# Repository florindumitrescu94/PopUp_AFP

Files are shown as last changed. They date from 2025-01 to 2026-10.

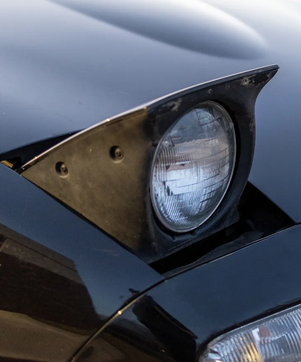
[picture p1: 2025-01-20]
PopUp_AFP/popup.png

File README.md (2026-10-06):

front

ASCOM connected DIY Automatic Flat Panel with Arduino and LED Strip.

Linux / INDI users: see [`PopUp_AFP_INDI/`](PopUp_AFP_INDI/) for a native INDI driver talking to the same Arduino firmware — no ASCOM/Windows required.

While a number of DIY flat panel projects exist online already, I wanted to make my own.
This is a flat panel with a spin: The motor and circuit board are on the panel itself, not on the telescope mounted base.
This allows the whole thing to be more low profile than existing designs. One advantage is the fact that no fragile wires will flex during operation. While there still are some wires present (the USB and Power cables), these wires can be swapped out at any time easily and without the need to open up the device.

This functions like any other flat panel (sans the dew heater available on some) and can be used in any imaging software that has ASCOM capabilities.

The BOM is fairly short: 
  - An Arduino Nano
  - a small buck converter to get 5V from 12V https://vi.aliexpress.com/item/1005007092498838.html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
  - TD-7120MG 270 degrees stepper motor https://vi.aliexpress.com/item/1005007475952814.html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
  - LR2905 N-MOSFET (SMD mounted)
  - a through-hole ferrite bead
  - 10k and 100 ohms SMD 0805 resistors
  - 1 SS545L SMD diode 
  - 1 through hole current limiting resistor for the LED strip (I went with 330 ohms, pick your own value based on your needs.
  - a length of 8mm wide natural white COB led strip (any 12V COB LED Strip will work. I sourced mine locally from a store, you could order one from AliExpress and you'd probably get the same thing).
  - a 12W round LED light fixture (links below). We will use this for the internal diffuser: https://vi.aliexpress.com/item/33054747819.html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

  To avoid flickering, the frequency of pin 3 has been increased to 31kHz and a ferite bead has been introduced in the circuit between the switching MOSFET and the LED strip. A flyback diode has been added to avoid any spikes created by the ferrite bead. It provides banding-free flats down to 0.1s. 

  The light panel is based around the 12W LED light diffuser. Once you get the light fixture, unscrew the 6 screws on the back and remove the round metal cover. Inside, you should find a round piece of white foam, a white plastic reflector, a disk of transparent acrylic and a white plastic translucent diffuser (the outside part). This is all we need from this light fixture.

The arms and base are printed in 3 parts: the two arms and the cross-brace that holds them in place with screws. Once you print the parts, align the two arms and the crossbrace, then drill 2mm holes in the brace through the already modeled holes in the arms. Then, insert either M3 screws and tighten down. Avoid overtightnening to not strip out the plastic. If you want, you can drill out bigger holes and use heat-set inserts. This base will be held in place on the telescope using metalic hose clamps. Make sure to stick some self-adhesive velvet on the dew shield to avoid scratching the metal. 



Print the four parts of the panel (BASE,RING,SPACER and SUPPORT), then assemble as follows:

- use 6 x 8mm M3 screws and nuts and connect the BASE to the SUPPORT using pre-modeled holes in the BASE. You can add some epoxy on the screw heads to stick them to the base for ease of later adjustment.
- solder two wires to the LED strip, the stick it around the inside of the BASE. You will need to overlap the last 2-3 mm of the strip after cutting it on the closest cutting point. To do that strip back the 2-3mm off the silicone cover from the LED strip and stick the end with the wires on top of that. Thread the wires thorugh the hole in the center of the BASE (it comes out through the SUPPORT into the electronics chamber)
- Put the foam piece in the center. You might want to cut a channel for the wires into the foam.
- Add the thin white reflector
- add the acrylic disk in the center
- add the 2.2mm 3d printed spacer ring
- put the translucent white diffuser on top
- add the 3d printed ring, align the screw holes with the ones in the base and screw in 6 x 4mm M3 bolts. You can use the bolts that came with the servo motor, since we will be using different bolts to secure the arm to the servo.

This concludes building the panel itself.

Next, cut, etch, drill and assemble the PCB, then put it inside the electronics case (PCB is in the Construction folder.
Schematic

I suggest cutting a 40mm x 60mm board so it fits snuggly against the walls of the SUPPORT. Solder the servo motor wires and the LED strip wires to the PCB. 
Then, drill four M3 holes in the PCB and the plastic risers, then screw the PCB down, avoiding overtightnening the screws. Make sure you print the risers with 100% infil.
Secure the SERVO in the SUPPORT bracket using the plastic screws that came supplied with the motor. 
Print the COVER, then secure it using M3 bolts, two on top and two on the sides.

At this point, the flat panel can be used as is. If you intend to build and use the panel as a manual panel, instead of a motorised one, you can follow the same procedure, but skip adding the motor. Skip the next step if you want this.

Mounting everything together:

Add the two metal wheels to the servo. Secure the one on the driven axle of the servo using the included M3 bolt. Use another M3 bolt for the support axle (the black plastic one that does not rotate). 
Next, loosely mount the ARMS and CROSS-BRACE to the telescope, then slide the SERVO motor shafts between the two arms. The arms have slotted holes, so the 0 position can be adjusted (the splined shaft holes do not end up perfectly aligned at 90 degrees).
DO NOT INSERT THE SCREWS MOUNTING THE ARMS TO THE SERVO YET! We need to make sure where the servo is currently positioned (0 to 270 degrees).
Print the cable clips and glue them to the ARM you want you cables to be attached to (use superglue or epoxy). 

Programing the board and driver setup:

Open Arduino IDE on your computer and connect the Arduino. Download the INO file from the release page and open it in the IDE. Select the correct COM port and board type, then upload the code. 
Download and install the ASCOM driver from the release page. 
Once installed, open N.I.N.A (or whatever aquisition software you are using), then select PopUp AFP. Warning: due to some reasons unknown to me, the ASCOM driver installer creates two entries in the dropdown selection menu. One of them works, but one of them is not registered with ASCOM, so it won't work. Check to see whcih one works and use that one. Open the properties, select the right COM port and set the Closed and Open positions (0 to 270 degrees), then hit Ok, then Connect to the device. 

Once connected, it's time for testing. Plug in a 12V power source and toggle the light panel on and off, setting different light levels (0 - 255). 
If you've used a jumper instead of a limiting resistor, the 255 value will be extremely bright. Now it's time to check and chose the right current limiting resistor for your situation (I've used 330 ohms and it works fine).
Then, click Open and Close and watch for movement of the stepper motor (remember, we do not have any screws mounted, so only the stepper flanges will move, but not the whole panel). 

Setting the Closed and Open Positions (angles) and the physical 0 position.

Earlier, when setting up the driver in NINA, we had to select an Open and Closed position for the panel. The Closed position should always be 0, but you can alter that in the unlikely eventuality you actually need to change it. 
Now, open the panel manually and check how much can it open. Measure the angle starting from the 0 position, then set that as Open position.
When there's no obstruction to the panel, it can fully open. Set the Open position to 270. This will open the panel fully, then set it parralel to the telescope


If theres any obstruction or, for any other reason, you need to open the panel lees than the full 270 degrees (which, with the TD7120MG is never really 270, more like 250-260), set the desired angle as Open position.





Set the two values, then connect to the device. Once connected, click the Close button.

Point your telescope at zenith, then close the panel manually. You might also need to adjust the position of the telescope-side mounting so that the panel can be flush with the dew shield's opening. 
At this point, you can insert the 8  M3 x 10mm bolts throught he slots in the arms and tighten them down. You can use some lock washers between the screw head and the arms, so it will bite into the plastic and not move. 

Once you have tightened the screws, click the Open button. The panel should now move to its' set max position. 

And..... that's it! You're ready to use the flat panel. 

Note on LED strips: 
I have used a warm white LED strip. While it looks very yellow-ish, the emissions in Ha and S2 are more intense than with cool/natural white. You can test and go with whichever colour temperature you might find fitting for your situation.

You can find the PCB copper file, EasyEDA project, Fusion 360 project and STL files inside the "Construction" folder

Note on Limiting Resistor:

During my time testing the panel, I've found that not using any current limiting resistor might work for a slow system, like mine, at f7. However, if you have a faster scope, you might benefit from adding a current limiting resistor instead of a jumper, so that you don't blow out the Luminance flats at 1% power.

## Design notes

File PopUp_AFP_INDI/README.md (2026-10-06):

# PopUp AFP — INDI driver

INDI driver for the PopUp AFP pop-up dust cover + dimmable flat panel, ported
from this repo's ASCOM `ICoverCalibrator` driver (`PopUp_AFP/CoverCalibratorDriver/`)
so the panel can be used from INDI/Ekos/KStars on Linux instead of (or
alongside) Windows + ASCOM.

It talks to the same Arduino sketch — `PopUp_AFP_Arduino/PopUp_AFP_Arduino_V2_CURRENT/PopUp_AFP_Arduino_V2.ino`
— over the same 9600-baud, `>CMD#`-framed serial protocol. No firmware changes
are required; flash the Arduino exactly as the main README already describes.

## Building

Dependencies: an INDI installation with headers (`libindi-dev`), cmake, a C++17
compiler, and pkg-config.

```bash
sudo apt install libindi-dev indi-bin cmake build-essential pkg-config
```

```bash
mkdir build && cd build
cmake ..
make
sudo make install
```

`make install` drops the driver at `/usr/local/bin/indi_popup_afp` and its
driver descriptor at `/usr/share/indi/indi_popup_afp.xml` — the two locations
a **native** `indiserver`/INDI Web Manager install scans automatically, so
nothing else needs registering there.

If `/dev/ttyUSB*` or `/dev/ttyACM*` isn't writable by your user, add yourself
to the serial port's owning group (usually `dialout`) and re-login:

```bash
sudo usermod -aG dialout $USER
```

### KStars installed as a Flatpak

If KStars/Ekos is a Flatpak (`org.kde.kstars` — increasingly the default way
it's distributed on Linux), the above is not enough, for two reasons:

1. **It doesn't read `/usr/share/indi/*.xml` at all.** Its Auxiliary driver
   list for a custom driver comes from a `customdrivers` table in its own
   SQLite db (`~/.var/app/org.kde.kstars/data/kstars/userdb.sqlite`), normally
   populated via the "add a custom driver" control in the Ekos Profile
   Editor's Auxiliary dropdown (enter Name/Label/Family `Auxiliary`/Exec
   `indi_popup_afp`/Version `1.0`).
2. **The sandbox can't see `/usr/local/bin`**, even with the Flatpak's broad
   `host` filesystem permission — its `/usr` belongs to the KDE runtime, not
   the host, so `indiserver` fails to exec the driver by name and the device
   just hangs (Ekos shows the device icon stuck, never reaching "connected").
   `$HOME` *is* visible to the sandbox, so install the binary there instead
   and give the custom driver's Exec field that **absolute path**, e.g.:

   ```bash
   mkdir -p ~/.local/bin
   cp build/indi_popup_afp ~/.local/bin/indi_popup_afp
   ```

   then set Exec to `/home/<you>/.local/bin/indi_popup_afp` rather than the
   bare `indi_popup_afp`, in the Ekos custom-driver dialog.

## Using it

Once installed, "PopUp AFP" appears under the Auxiliary device group in any
INDI client. Connect, set the serial port on the Connection tab if it isn't
already `/dev/ttyUSB0`, and the Main Control tab gets:

- **Cover Park / UnPark** — closes/opens the pop-up cover (`>CLOSE#` / `>OPEN#`)
- **Flat Light Control** on/off, plus a 0-255 **Flat Field Light Level** —
  matches the ASCOM driver's `CalibratorOn(Brightness)` / `CalibratorOff()`

The Options tab has **Servo Calibration** (Open/Closed, in degrees 0-270),
replacing the ASCOM SetupDialog's Open/Closed position fields — same values
the main README has you set in NINA (fully open = 270, closed = 0). These are
re-sent to the Arduino on every connect, since the firmware keeps them in RAM,
not EEPROM.

## Known firmware limitation

`AbortCap()` sends `>HALT#`, but `PopUp_AFP_Arduino_V2.ino`'s
`processSerialCommand()` has no `HALT` case today, so it's a no-op on the
device — same as the ASCOM driver's `HaltCover()`. Abort will start working on
its own the day the firmware grows a case for it; no driver change needed.

## What's not yet verified

This was built and compiled against a real `libindi-dev` and passed a smoke
test of the INDI property handshake, but has not been run against the actual
Arduino. Before trusting it on a real panel, verify:

- the serial port name/permissions on the test machine
- that `OPEN`/`CLOSE` actually move the cover through its full range at the
  configured servo angles
- that brightness changes while the light is already on take effect
  immediately (vs. only on the next `EnableLightBox(true)`)

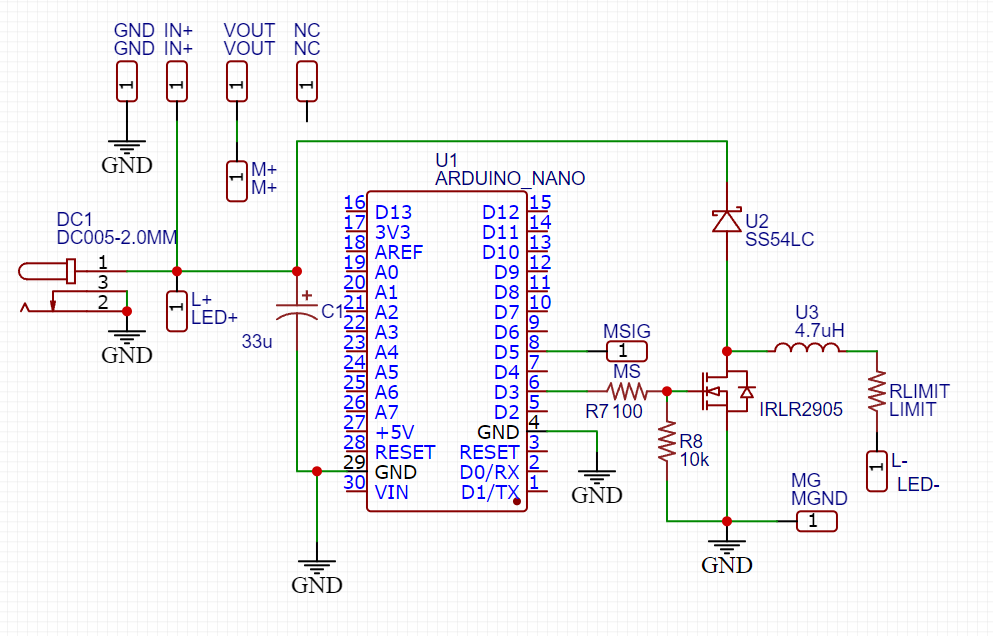
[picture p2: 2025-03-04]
Construction/V2_CURRENT/Schematic.png

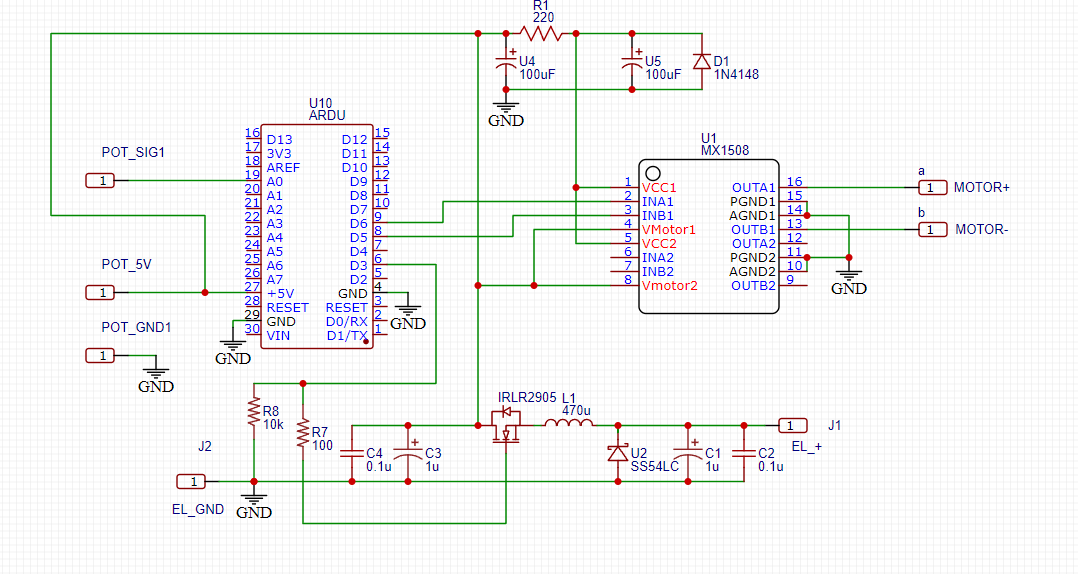
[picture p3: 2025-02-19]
Construction/schematic.png

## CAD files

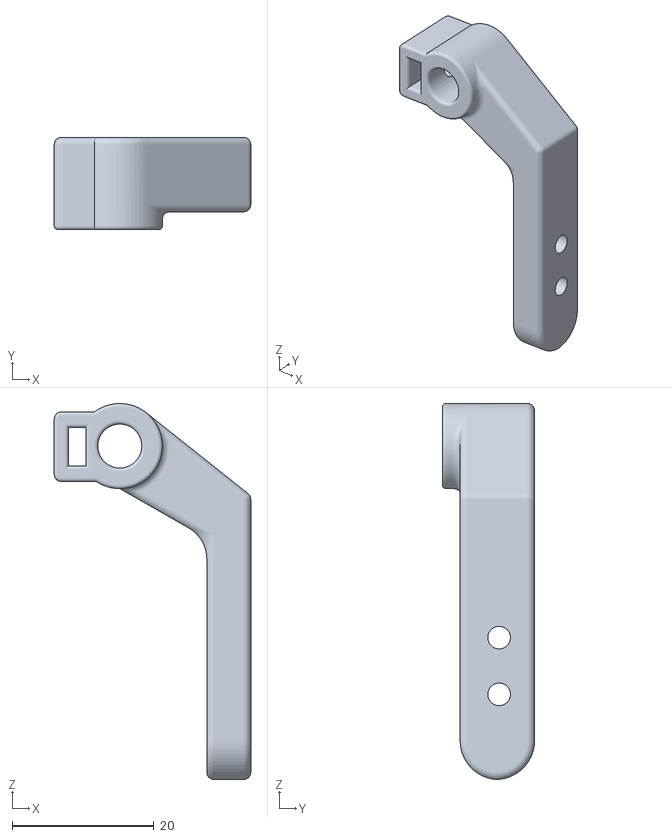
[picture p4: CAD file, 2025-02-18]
Construction/Pop_Up_Arm_Pot_model.stl
27.7 x 13.0 x 53.0

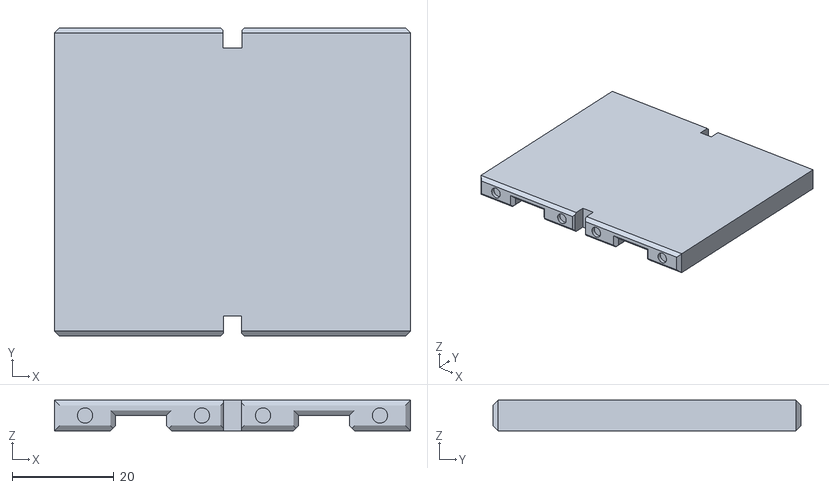
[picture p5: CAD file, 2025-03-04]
Construction/V2_CURRENT/SLT_Files/CROSS_BRACE.stl
70.0 x 60.6 x 6.00

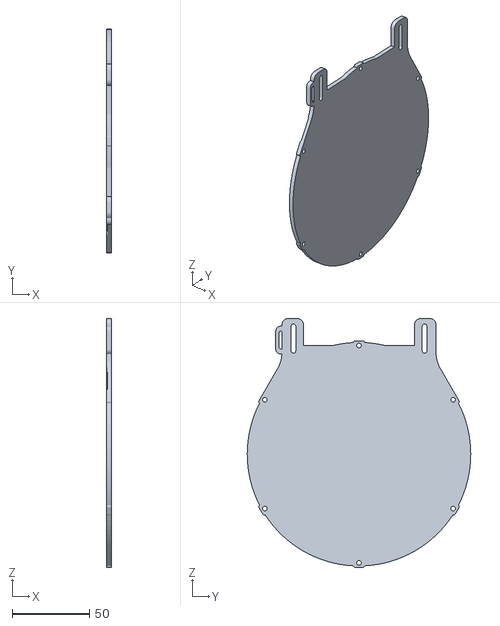
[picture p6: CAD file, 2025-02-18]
Construction/Pop_Up_Base_model.stl
3.00 x 145.0 x 161.5

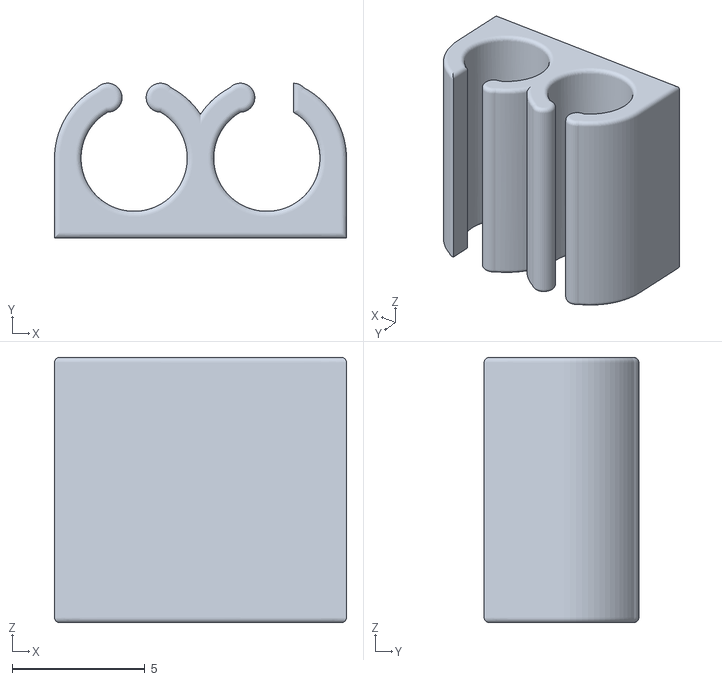
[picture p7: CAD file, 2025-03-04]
Construction/V2_CURRENT/SLT_Files/CLIPS.stl
11.0 x 5.83 x 10.0

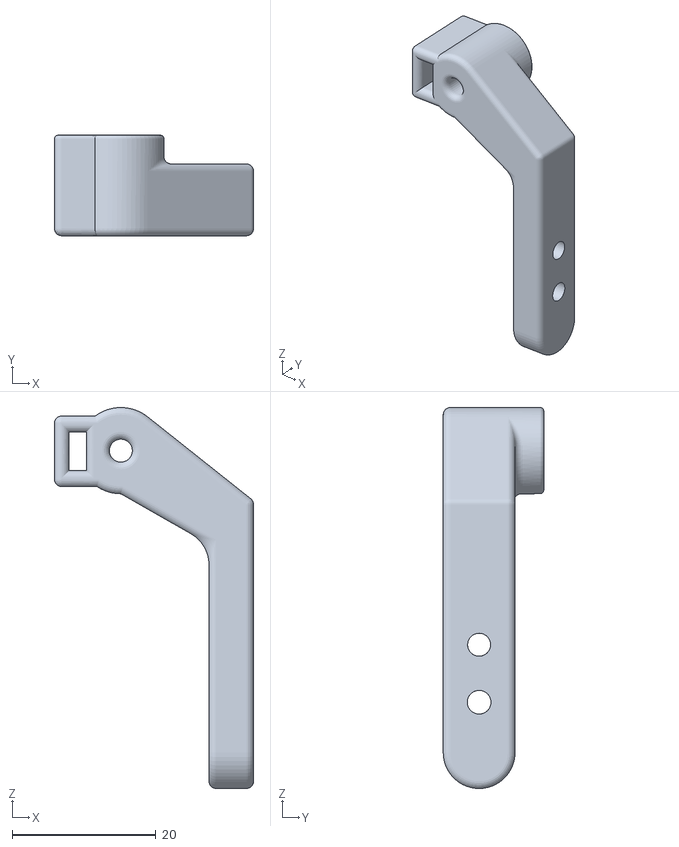
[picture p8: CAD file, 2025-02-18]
Construction/Pop_Up_ArmMotor_model.stl
27.7 x 14.0 x 53.0

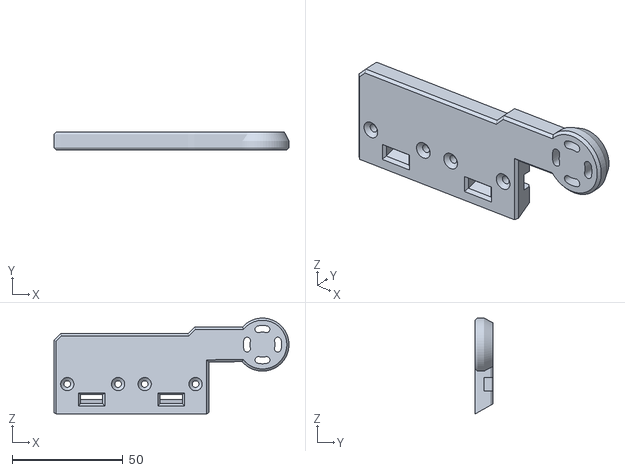
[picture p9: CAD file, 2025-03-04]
Construction/V2_CURRENT/SLT_Files/ARM_R.stl
106.2 x 8.00 x 43.3

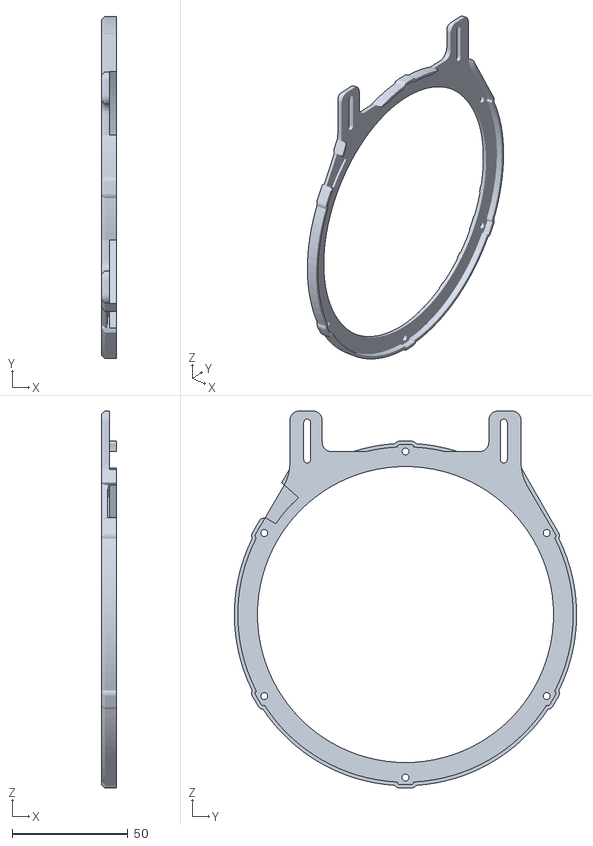
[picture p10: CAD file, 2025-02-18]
Construction/Pop_Up_Ring_model.stl
6.50 x 148.0 x 163.0

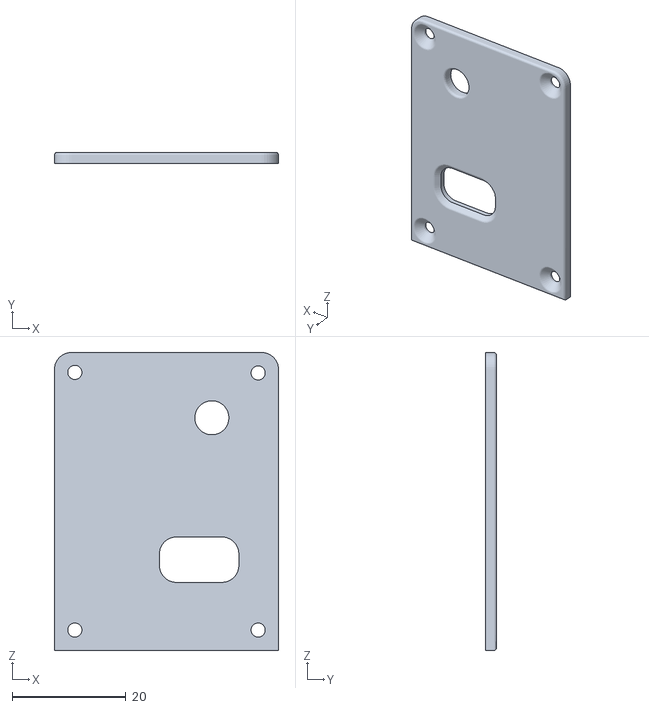
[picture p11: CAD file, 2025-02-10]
Construction/Pop_Up_EndCap_model.stl
39.5 x 2.00 x 52.5

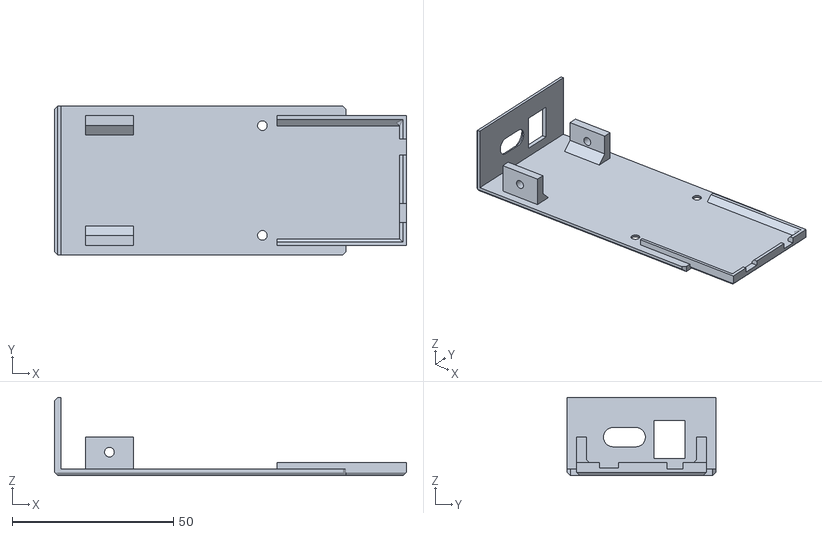
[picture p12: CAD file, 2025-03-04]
Construction/V2_CURRENT/SLT_Files/COVER.stl
109.2 x 46.2 x 24.2

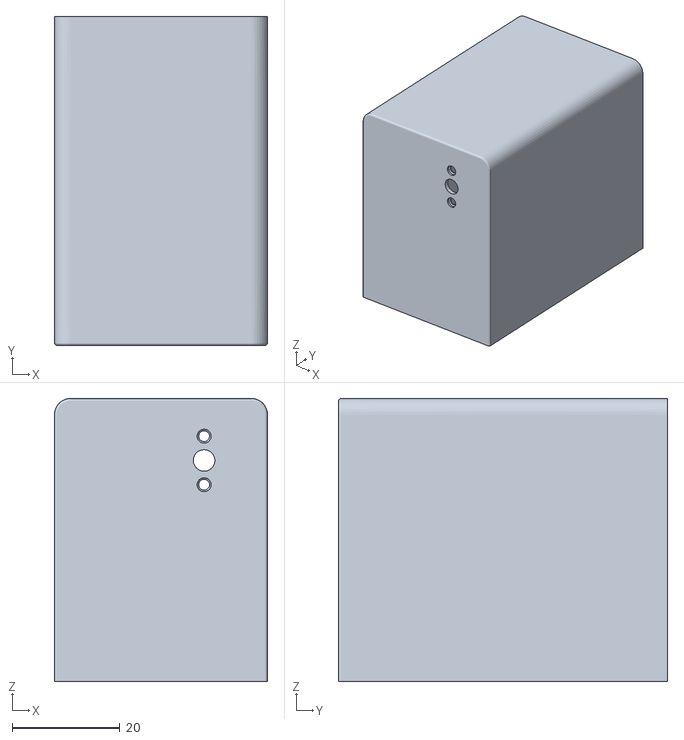
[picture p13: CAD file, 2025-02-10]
Construction/Pop_Up_Body_model.stl
39.5 x 61.0 x 52.5

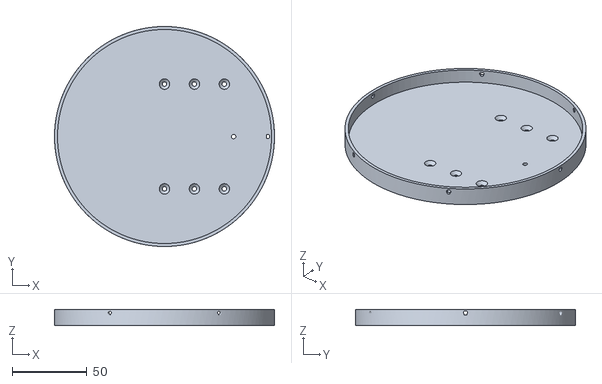
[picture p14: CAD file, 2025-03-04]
Construction/V2_CURRENT/SLT_Files/BASE.stl
147.0 x 147.0 x 11.0

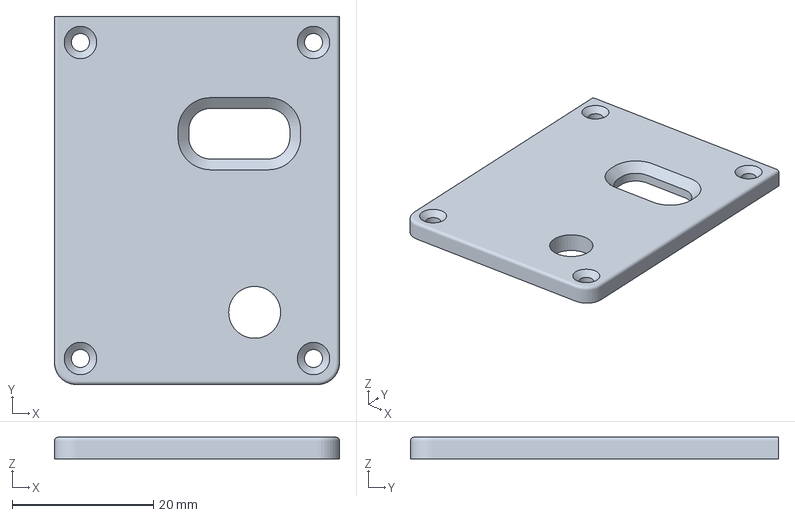
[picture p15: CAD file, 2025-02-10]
Construction/potentiometer_cap_102.3mf
40.3 x 52.0 x 3.06 mm

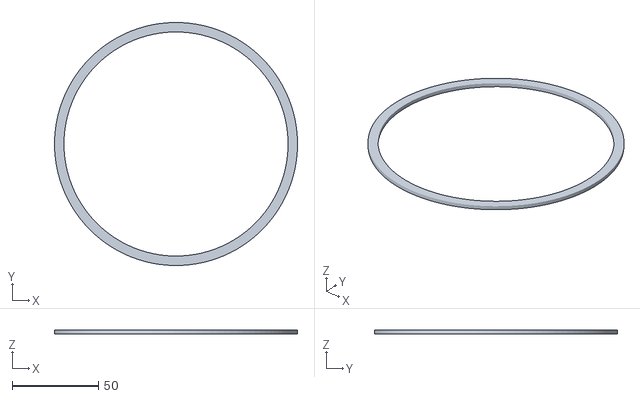
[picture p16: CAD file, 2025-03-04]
Construction/V2_CURRENT/SLT_Files/SPACER.stl
141.0 x 141.0 x 2.20

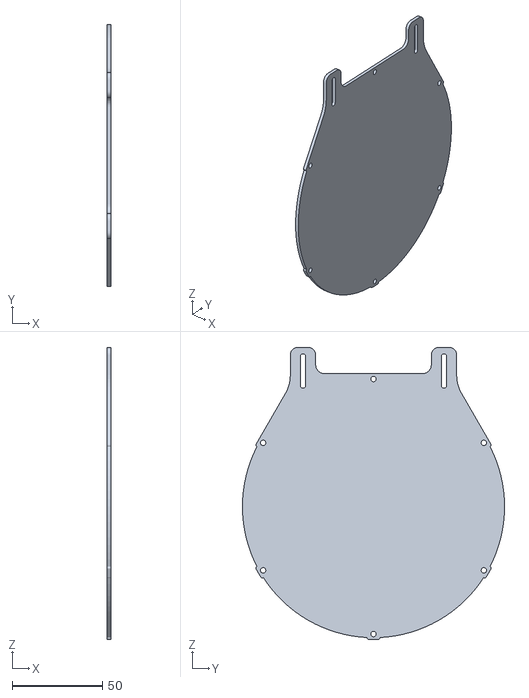
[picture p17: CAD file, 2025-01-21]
Construction/Pop_Up_Plexiglass_model.stl
2.00 x 145.0 x 161.5

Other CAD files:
Construction/V2_CURRENT/SLT_Files/ARM_L.stl
Construction/V2_CURRENT/SLT_Files/RING.stl
Construction/V2_CURRENT/SLT_Files/SUPPORT.stl
Construction/V2_CURRENT/PopUp_V2.f3z

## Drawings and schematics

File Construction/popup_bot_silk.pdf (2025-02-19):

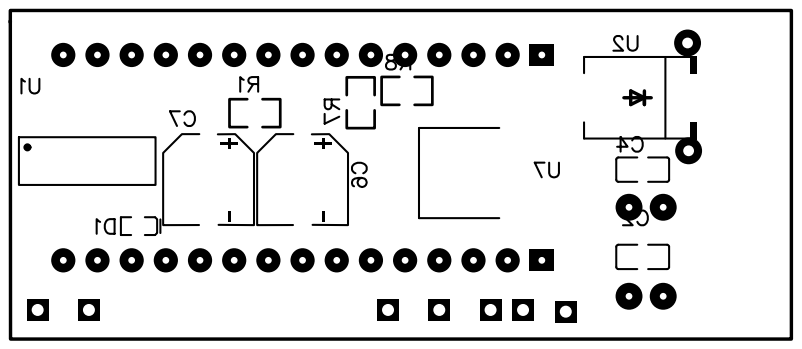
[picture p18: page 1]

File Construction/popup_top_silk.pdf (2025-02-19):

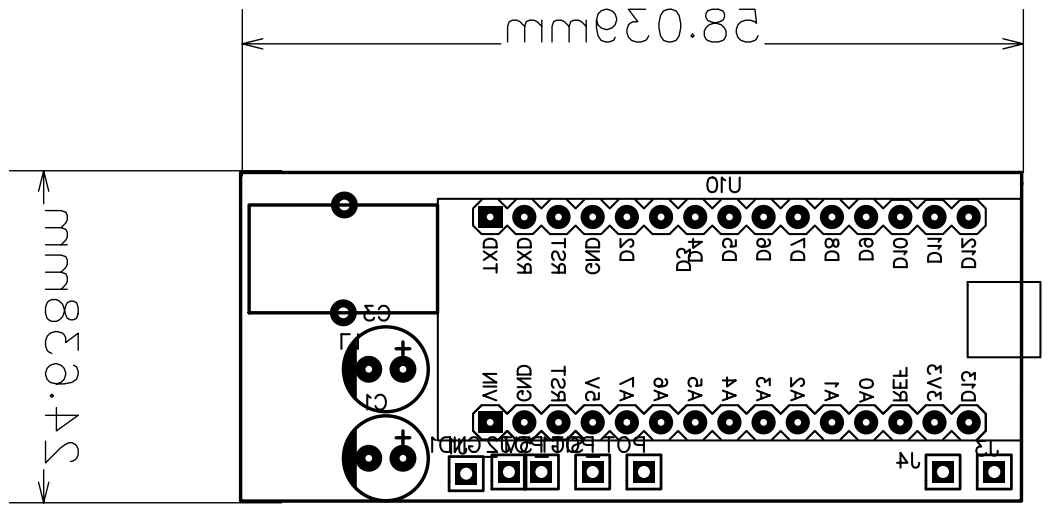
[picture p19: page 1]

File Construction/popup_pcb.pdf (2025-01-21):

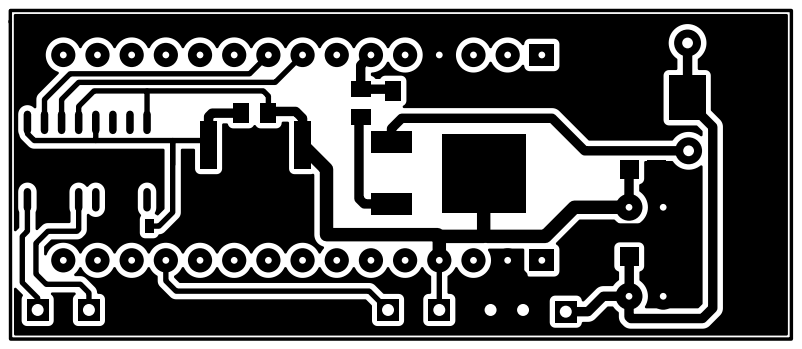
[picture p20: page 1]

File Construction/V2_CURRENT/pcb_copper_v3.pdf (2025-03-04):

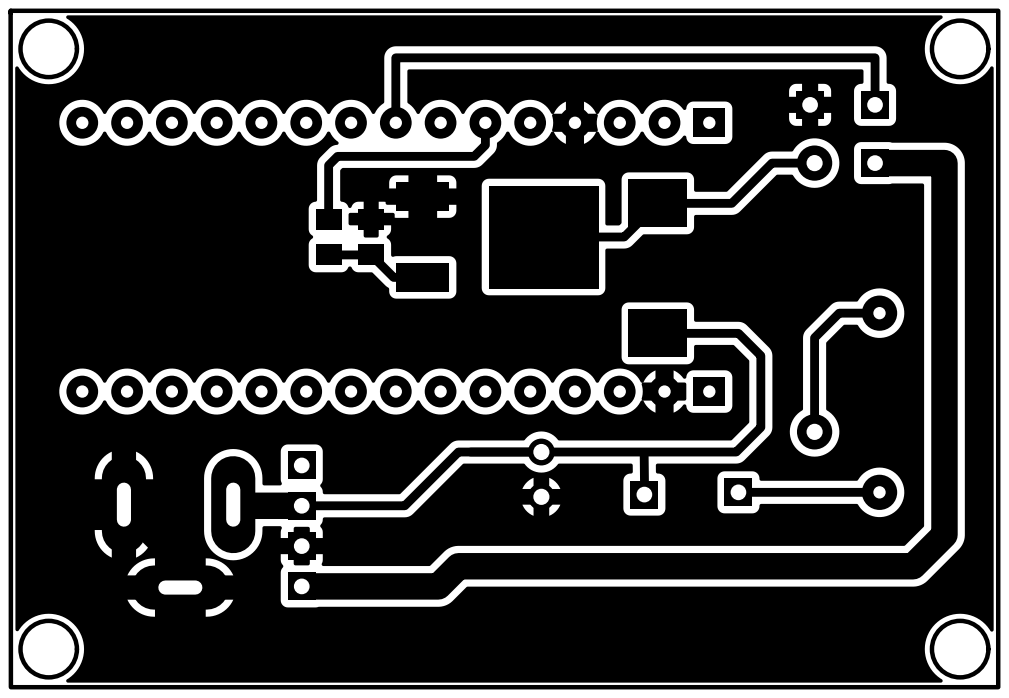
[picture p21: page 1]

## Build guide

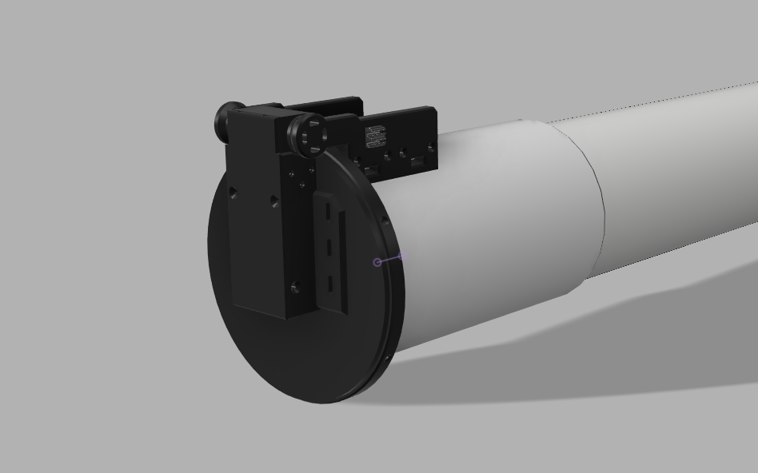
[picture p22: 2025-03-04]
Construction/V2_CURRENT/Render/front.png

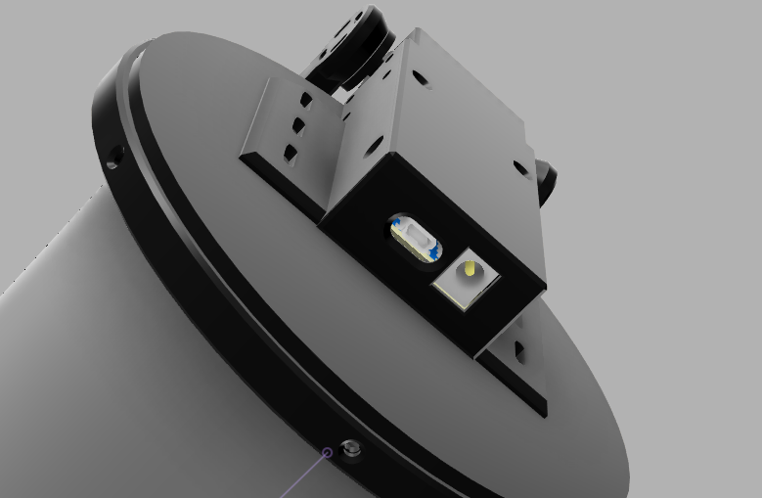
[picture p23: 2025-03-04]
Construction/V2_CURRENT/Render/ports.png

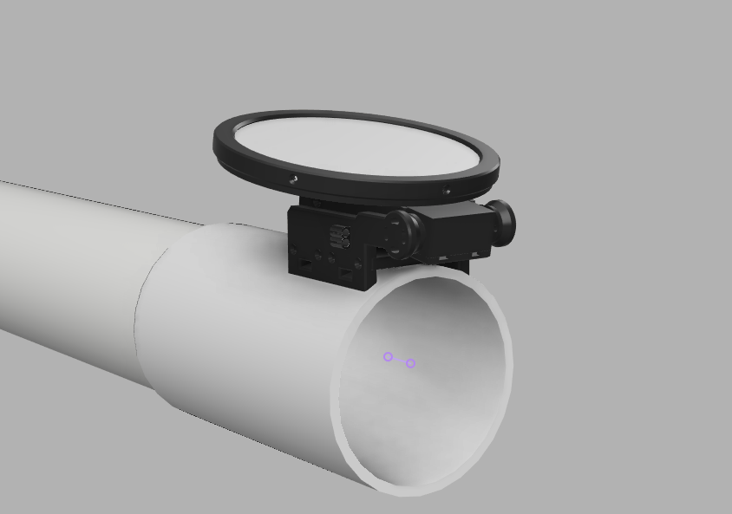
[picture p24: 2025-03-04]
Construction/V2_CURRENT/Render/Opened.png

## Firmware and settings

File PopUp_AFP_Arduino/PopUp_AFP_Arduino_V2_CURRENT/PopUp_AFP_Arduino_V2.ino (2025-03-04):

#include <math.h>
#include <Servo.h>
#include <EEPROM.h>
#define MOTOR 5
#define LIGHT 3
#define QUEUELENGTH         10             // number of commands that can be saved in the serial queue
#define MAXCOMMAND          42            // max length of a command
#define EOFSTR              '\n'
#define EOCOMMAND           '#'           // defines the end character of a command
#define SOCOMMAND           '>'           // defines the start character of a command
#define ADDR 1 // defines eeprom address

Servo PanelServo;
int panel_light=0; // State for panel light
int eeprom_position = 0; // state for EEPROM position
int panel_brightness=0; // Value for panel light 0-255
int panel_position;
int panel_state=0; //0 = Closed. 1 = Open 2 = Unknown 3 = Error 4 = Moving
int panel_closed_pos=0; // define close position
int panel_open_pos=270; // define open position
int target_state = 3; // used to hold target state (close = 0 , open = 1, done = 3, halt  = 4). Initialize with 3
char* queue[QUEUELENGTH];
int queueHead = -1;
int queueCount = 0;
int idx = 0;                              // index into the command string
String line;       

char* pop() {
  --queueCount;
  return queue[queueHead--];
}


void push(char command[MAXCOMMAND]) {
  queueCount++;
  queueHead++;
  strncpy(queue[queueHead], command, MAXCOMMAND);
}

void setup() {
  TCCR2B = TCCR2B & B11111000 | B00000001;
  pinMode(LIGHT,OUTPUT);
  pinMode(MOTOR,OUTPUT);
  analogWrite(LIGHT,0); // Set panel light to off
  eeprom_position = EEPROM.read(ADDR);
  if (eeprom_position == 1) PanelServo.write(panel_open_pos);
  if (eeprom_position == 0) PanelServo.write(panel_closed_pos);
  PanelServo.attach(MOTOR); // Attach servo
  panel_state = 2; // Panel position will be unkown at beginning;
  for ( int i=0; i < QUEUELENGTH; i++)
  queue[i] = (char*)malloc(MAXCOMMAND);
  line.reserve(MAXCOMMAND);
  Serial.begin(9600); // begin seral comm over com port
  Serial.flush();
}

void clearSerialPort() {
  while ( Serial.available() )
    Serial.read();
}

// SerialEvent occurs whenever new data comes in the serial RX.
// you should really consider a start of command character.
void serialEvent() {

  // '#' ends the command, do not store these in the command buffer
  // read the command until the terminating # character
  char buf[MAXCOMMAND];
  while ( Serial.available() )
  {
    char inChar = Serial.read();
    switch ( inChar )
    {
      case '>':     // soc, reinit line
        // memset(line, 0, MAXCOMMAND);
        line = "";
        idx = 0;
        break;
      case '#':     // eoc
        line.toCharArray(buf, MAXCOMMAND);
        idx = 0;
        push(buf);
        break;
      default:      // anything else
        if ( idx < MAXCOMMAND - 1) {
          line += inChar;
        }
        break;
    }
  }
}

void processSerialCommand(){
   if ( queueCount == 0 )
    return;

  String cmd = String(pop());
  if (cmd == "OPEN")
  {
   PanelServo.write(panel_open_pos);
   panel_state = 1;
   EEPROM.write(ADDR,panel_state);
  }
  else if (cmd == "CLOSE")
  {
    PanelServo.write(panel_closed_pos);
    panel_state = 0;
    EEPROM.write(ADDR,panel_state);
  }
  else if (cmd.substring(0,7) == "LIGHTON") 
  {
      panel_brightness = (cmd.substring((cmd.indexOf('_')+1),(cmd.indexOf('_')+4)).toInt());
      analogWrite(LIGHT,panel_brightness); // turn on light with set brightness
      panel_light = 1;
      //Serial.print(panel_light);
      //Serial.println("#");
  }
  else if (cmd == "LIGHTOFF") 
  {
      analogWrite(LIGHT,0); // turn on light with set brightness
      panel_light = 0;
  }
  
  else if (cmd == "GETLIGHTSTATE")
  {
    Serial.print(panel_light);
    Serial.print("#");
  }
  else if (cmd == "GETSTATE")
  {
    Serial.print(panel_state);
    Serial.print("#");
  }
  else if (cmd == "GETLIGHT")
  {
    Serial.print(panel_brightness);
    Serial.print("#");
  }
  else if (cmd == "GETPOSITION")
  {
    Serial.print(panel_position);
    Serial.println("#");
  }
  else if (cmd.substring(0,7) == "SETOPEN") 
  {
    panel_open_pos = (cmd.substring((cmd.indexOf('_')+1),(cmd.indexOf('_')+5)).toInt());
  }
  else if (cmd.substring(0,9) == "SETCLOSED") 
  {
    panel_closed_pos = (cmd.substring((cmd.indexOf('_')+1),(cmd.indexOf('_')+5)).toInt());
  }
}

void loop() {

  if ( queueCount >= 1 ) {               // check for serial command
    processSerialCommand();
  }
}

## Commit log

2025-01-20 Set name in Chooser. Added Arduino firmware file
2025-01-20 Added Arduino firmware
2025-01-21 Update PopUp_AFP_Arduino.ino
    increased pin 3 pwm frequency to 31kHz
2025-01-21 Upload construction files
    Uploaded all construction files and models
    [Pop_Up_ArmMotor_model.stl, Pop_Up_Arm_Pot_model.stl, Pop_Up_Base_model.stl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]
2025-01-21 Removed unnecessary code, added CoverState.Error state
    [PopUp_AFP_Arduino.ino]
2025-01-21 Update PopUp_AFP_Arduino.ino
    Updated Arduino code to include Error and Moving + watchdog
    [PopUp_AFP_Arduino.ino]
2025-02-10 Updated model to allow the use of a regular potentiomter
    [(Unsaved).stl, Pop_Up_Body_model.stl, Pop_Up_EndCap_model.stl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]
2025-02-18 updated models for base, ring and arms
    Redesigned panel and arms for better strength.
    [Body1.stl, Pop_Up_ArmMotor_model.stl, Pop_Up_Arm_Pot_model.stl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]
2025-02-18 Incrreased backlash compensation for Close action
    Increased backlash compensation for close action from 320 to 420.
    [PopUp_AFP_Arduino.ino]
2025-02-19 Created ZIP file with 3dmodels
    [(Unsaved).stl, Body1.stl]
2025-03-04 reorganizsed files
    [Pop_Up_ArmMotor_model.stl, Pop_Up_Arm_Pot_model.stl, Pop_Up_Base_model.stl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]
2025-03-04 created stl files, fusion360 project and easyeda project
    [ARM_L.stl, ARM_R.stl, BASE.stl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]
2025-05-03 Uploaded gerber files
2025-05-03 Update README.md
    Updated LED strip info
2025-05-03 Update README.md
    Added note on limiting resistor
2026-10-06 feat: add an INDI driver for Linux/Ekos users (#5)
    * feat: add an INDI driver for Linux/Ekos users, alongside the ASCOM one
    Talks to the same PopUp_AFP_Arduino_V2.ino sketch over the same 9600-
    baud ">CMD#" serial protocol, so no firmware changes are needed. Maps
    cover open/close to INDI's DustCapInterface (Park/UnPark) and the
    light on/off/brightness to LightBoxInterface, with an Options-tab
    Servo Calibration property replacing the ASCOM SetupDialog's Open/
    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
